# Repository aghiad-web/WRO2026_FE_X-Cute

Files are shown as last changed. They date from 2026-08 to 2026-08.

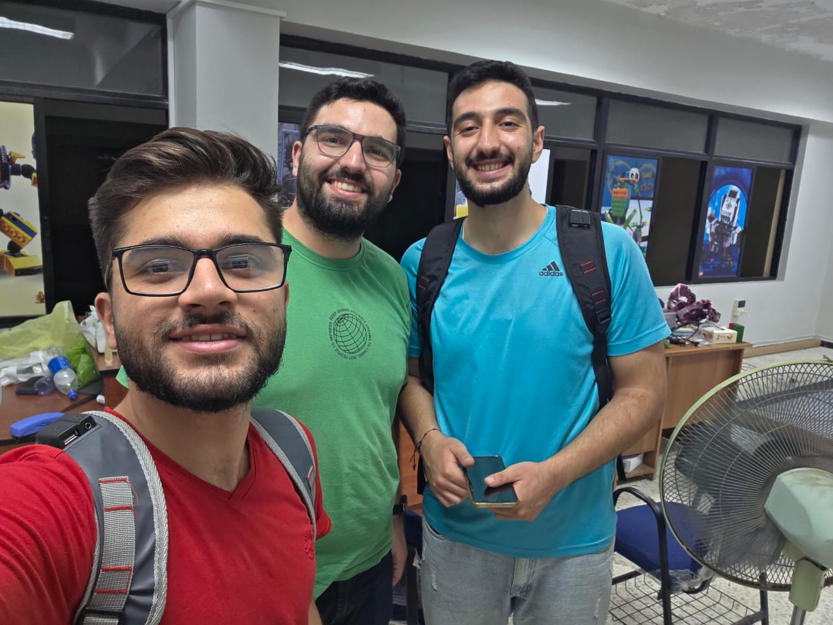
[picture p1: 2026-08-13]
t-photos/Team Photo .jpeg

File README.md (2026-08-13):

# WRO 2026 — Future Engineers | Team X-CUTE

Engineering documentation for the self-driving vehicle built by **Team X-CUTE** for the World Robot Olympiad 2026 Future Engineers category.

---

## Content

| Folder | Description |
|---|---|
| `t-photos` | Team photos — one official group photo and one informal/fun photo |
| `v-photos` | Vehicle photos from all six angles (front, back, left, right, top, bottom) |
| `video` | Link to the driving demonstration videos |
| `schemes` | Electromechanical schematics — wiring diagrams, PCB schematic and layout |
| `src` | All source code — Raspberry Pi vision/control scripts and STM32 firmware |
| `models` | 3D-printable models (STL) and SolidWorks source files for custom parts |
| `other` | Supporting files — datasheets, cost report, assembly notes |

---

## 1. Introduction

Our robot bridges advanced computer vision for strategic decision-making with real-time motion control. The vehicle uses an **Ackermann steering mechanism** and a hybrid sensory system that combines Time-of-Flight laser sensors for high-accuracy distance measurement with ultrasonic sensors acting as a fast-response safety and wall-following layer.

High-level visual perception runs on a **Raspberry Pi 5**, while an **STM32F411 microcontroller** executes real-time PID control. This separation ensures seamless navigation, dynamic obstacle dodging, and precise final parking.

---

## 2. The Team

**Team X-CUTE**

| Role | Name |
|---|---|
| Coach | Aghiad Jomah |
| Member | Mohamad Alzoubi |
| Member | Elias Kuzma |

Our team integrates embedded systems engineering with computer vision to build self-driving vehicles capable of analyzing their environment and making independent, reliable navigational decisions in dynamic conditions.

> Team photos are in [`t-photos`](t-photos).

---

## 3. Mobility Management

### 3.1 Chassis Design

The chassis was precision-designed in **SolidWorks** and fully 3D-printed, divided into three functional layers to balance weight distribution, mechanical isolation, and cable routing:

| Layer | Contents | Purpose |
|---|---|---|
| **Top (3rd)** | Custom PCB, STM32F411, camera module | Elevating the camera gives a clear, wide field of view for accurate track and pillar detection |
| **Middle (2nd)** | Raspberry Pi 5, motor driver | High-level processing and decision-making hub |
| **Bottom (1st)** | Drive motor, steering servo, battery | Places the heaviest components lowest for a low centre of gravity and stability during sharp cornering |

### 3.2 Custom 3D-Printed Parts

All source models are available in [`models`](models).

- **Three main chassis layers** — custom lightweight structure with pre-designed mounting holes, integrated standoffs, and optimised cable routing paths.
- **Ackermann steering knuckles** — designed to achieve the exact Ackermann geometry for our wheelbase, with optimised pivot points for maximum steering angle without wheel scrub.
- **DC motor mount** — secures the Ga25 motor and maintains alignment between the motor shaft and differential gear to prevent power loss.
- **Ultrasonic sensor holders** — set the mounting height and angle to detect track walls reliably while avoiding false floor reflections.
- **Laser sensor mounts** — hold the VL53L0X modules at a fixed angle for accurate pillar targeting.

### 3.3 Steering — Ackermann Geometry

Ackermann geometry allows the inner wheel to steer at a sharper angle than the outer wheel, minimising tire slip and scrub while maintaining an optimal centre of rotation.

Where `w` is the track width, `l` the wheelbase, `φᵢ` the inner wheel angle, `φₒ` the outer wheel angle, and `r` the distance from the instantaneous centre of curvature (ICC) to the vehicle centre:

```
tan(φ)  = l / r
tan(φᵢ) = l / (r − w/2)
tan(φₒ) = l / (r + w/2)

φᵢ = arctan( 2l·sin(φ) / (2l·cos(φ) − w·sin(φ)) )
φₒ = arctan( 2l·sin(φ) / (2l·cos(φ) + w·sin(φ)) )
```

Actuation uses a **DYNAMIXEL XL330 smart servo**. Unlike standard RC servos driven by PWM, it communicates over a half-duplex serial bus, letting the STM32 send precise angular commands and read back the exact motor position.

### 3.4 Drivetrain

| Component | Specification |
|---|---|
| **Drive motor** | Ga25 brushed DC gear motor — 12 V, ≈600 RPM, ≈10:1 gearbox, ≈0.4 kg·cm continuous torque, ≈1.2 A stall |
| **Steering servo** | DYNAMIXEL XL330 — 5 V, ≈5.3 kg·cm stall torque, UART/TTL half-duplex, internal PID with position/velocity/load/temperature feedback |
| **Differential** | Gear differential on the rear axle — allows the outer wheel to rotate faster while cornering, preventing skid |
| **Wheels** | Silicone — high grip and traction, minimising slippage under acceleration and braking |

---

## 4. Power and Sense Management

### 4.1 Sensors

| Sensor | Qty | Role |
|---|---|---|
| **VL53L0X** ToF laser | 2 | Primary sensor for precise dynamic pillar dodging — mm-level accuracy, up to 200 cm, 50 Hz, immune to ambient light |
| **US-100** ultrasonic | 3 | Wall-following and safety net — 2–450 cm, built-in temperature compensation for stable readings regardless of motor or ambient heat |
| **BNO085** 9-DoF IMU | 1 | Heading estimation via on-chip sensor fusion — ≈1.5° static / ≈3.5° dynamic accuracy, resistant to electromagnetic interference |
| **FANTECH LUMINOUS C30** camera | 1 | USB webcam, 2K @ 30 FPS, ≈106° ultra-wide FOV — line and pillar detection via OpenCV |

### 4.2 Drivers

- **IBT-4 DC Motor Driver** — high-current MOSFET H-bridge, 5–15 V, up to 50 A peak. Provides large headroom over the Ga25's 1.2 A stall current and protects against back-EMF during active braking. Interfaces directly with 3.3 V STM32 logic, no level shifters required.
- **Waveshare Serial Bus Servo Driver** — converts standard full-duplex UART to the half-duplex single-wire bus the XL330 requires, with hardware-level automatic TX/RX direction switching. Routes servo power separately, isolating motor current from logic circuits.

### 4.3 Controllers

Our system uses a **Hybrid Control Architecture** that separates high-level processing from low-level real-time motion control.

**Raspberry Pi 5 (8 GB)** — the brain. Runs Python control scripts and OpenCV computer vision, processes camera frames, applies the Y-axis depth-sorting algorithm for red and green pillars, and sends strategic commands to the STM32 over UART. The 2.4 GHz quad-core Cortex-A76 and 8 GB LPDDR4X allow 2K-resolution processing at high frame rates without bottlenecks.

**STM32F411 (BlackPill)** — the muscle. Receives strategic commands over UART and translates them into precise PWM motor signals, handles ultrasonic hardware interrupts, and reads the IMU. Linux is not designed for hard real-time tasks; the STM32 provides **deterministic execution**, ensuring PID calculations, motor updates, and sensor reads occur with microsecond precision and no jitter. Its hardware FPU accelerates the floating-point math the control loops require.

### 4.4 Power Management

The electrical system follows a **"Separation of Power Domains"** philosophy:

- **Logic power** — the Raspberry Pi and its camera run from a dedicated 20 W power bank. This complete isolation prevents OS brownouts caused by sudden current draw from the motors.
- **Actuator power** — a 3S Li-Po (11.1 V, 2200 mAh, 30C) supplies the lower layer. The high discharge rate delivers burst current for the motor and servo during acceleration and sudden stops without voltage sag.
- **Voltage regulation** — an XL4015 DC-DC buck converter steps 11.1 V down to a clean, regulated 5 V for the STM32 and sensors, at up to 96% efficiency with thermal shutdown and short-circuit protection.

<details>
<summary><b>Full current budget</b></summary>

| Component | Qty | Supply | Idle | Active | Peak/Stall |
|---|---|---|---|---|---|
| Raspberry Pi 5 (8 GB) | 1 | 5.0 V | ~600–800 mA | ~1.5–2.0 A | up to 5.0 A |
| FANTECH C30 camera | 1 | 5 V (Pi USB) | — | ~150–250 mA | ~300 mA |
| STM32F411 | 1 | 3.3 / 5 V | ~10 mA | ~25–35 mA | ~50 mA |
| BNO085 IMU | 1 | 3.3 V | ~3 mA | ~10–15 mA | — |
| US-100 ultrasonic | 3 | 5.0 V | < 2 mA | ~3–5 mA | — |
| VL53L0X laser | 2 | 3.3–5.0 V | < 5 µA | ~20 mA | ~40 mA |
| DYNAMIXEL XL330 | 1 | 5.0 V | ~15 mA | ~150–300 mA | ~1.5 A |
| Ga25 DC motor | 1 | 12 V | — | ~100–400 mA | ~1.2 A |
| IBT-4 driver | 1 | 5 V logic / 12 V load | ~2 mA | driver losses | 50 A peak rating |
| Waveshare servo driver | 1 | 5.0 V | ~2 mA | servo load pass-through | — |
| XL4015 converter | 1 | 12 V in / 5 V out | ~5 mA | load dependent | 5 A peak rating |

</details>

### 4.5 Custom PCB

To eliminate the unreliability of loose jumper wires and breadboards, we designed a custom PCB that acts as the central nervous system of the hardware — routing power and data between the STM32, sensor arrays, motor drivers, and the XL4015 power module.

The schematic enforces complete isolation between logic circuits and high-current actuators, with properly sized power traces, pull-up resistors on the I²C lines, and organised header pins. The layout accounts for EMI and thermal dissipation: the XL4015 and BlackPill are placed to minimise signal travel distance, and extensive copper ground pours provide a common reference and heat spreading.

> Schematics and layout files are in [`schemes`](schemes).

---

## 5. Obstacle Management

### 5.1 System Architecture

Rather than heavy middleware, we use a lightweight **Master–Slave architecture** over direct UART:

- **Master node** — Raspberry Pi 5 running Python. Captures frames, processes them via OpenCV, and issues strategic commands (`TURN_LEFT`, `DODGE_RIGHT`, …).
- **Execution node** — STM32F411. Receives short string commands and folds them into a **non-blocking Finite State Machine** that updates motor speeds and PID offsets without halting distance or IMU sensor reads.

### 5.2 Open Challenge — "Direction Lock"

The goal is three laps without wall contact in the shortest time. We run a wall-following algorithm on the ultrasonic sensors, driving the error between right and left distances toward zero with a PID controller.

For corners, the camera does not re-evaluate colour at every turn. On start, it monitors the floor: an **orange line first locks the direction as Clockwise**; a **blue line first locks Counter-Clockwise**. For the remaining 11 corners the robot turns according to the locked direction as soon as any line colour is seen — eliminating visual confusion and guaranteeing track stability.

### 5.3 Image Processing

Frames from the tilt-down camera are converted from RGB to **HSV** to resist colour fluctuation under changing light. We apply masks isolating the four relevant colours (blue, orange, red, green), run morphological filters to remove noise, and extract bounding boxes to determine each element's position and size in frame.

### 5.4 Obstacle Challenge — Y-Axis Depth Sorting

Pillars require higher spatial accuracy than corners. To handle complex scenes — for example red and green pillars in the same frame — we developed the **Y-Axis Depth Sorting** algorithm:

1. Collect the coordinates of all detected pillars and sort them in descending order by the lowest point of their bounding box (`bottom_y`).
2. Ignore all distant pillars; interact only with the pillar of highest `Y` value — the one nearest the front of the robot.
3. If the nearest pillar is **red**, the Pi sends `DODGE_RIGHT`; if **green**, `DODGE_LEFT`. The STM32 translates the command into a dynamic `Lane_Offset` bias inside the distance-sensor PID equation, smoothly hugging the corresponding wall.

Because the dodge is expressed as a PID bias rather than a discrete manoeuvre, the robot performs continuous slalom movement without ever needing to stop.

---

## 6. Performance Videos

| Challenge | Video |
|---|---|
| Open Challenge | *[link]* |
| Obstacle Challenge | *[link]* |

---

## 7. Problems We Encountered

| Problem | Solution |
|---|---|
| **Camera field of view** — the standard Pi camera's narrow FOV made it hard to see the full track width or spot peripheral pillars in time. | Replaced with the FANTECH C30 wide-angle webcam, letting the vision pipeline capture surrounding detail and recognise obstacles from a safe distance. |
| **Ackermann steering angle limits** — the initial mechanism capped our maximum steering angle, widening the turning radius and pushing the robot toward outer walls. | Redesigned the knuckles and tie rods in SolidWorks with optimised pivot points and lever lengths, significantly increasing front-wheel range of motion while preserving correct Ackermann intersection. |
| **Frame flickering** — room lighting and fluorescent lamp frequency destabilised our colour masks. | Disabled auto white balance and set shutter speed and exposure programmatically via OpenCV to match ambient lighting frequency. |
| **Processor data-flow desync** — continuous UART streaming from the Pi overflowed the STM32 buffer, delaying motor response. | Replaced streaming with a lightweight event-based protocol that sends short commands only on state change, plus a non-blocking FSM on the STM32 so serial reads never halt other operations. |
| **Merging pillar contours** — closely spaced pillars merged into one contour from the low camera perspective, misread as a single obstacle. | Raised the camera to the third layer and optimised its tilt-down angle, restoring visual separation and letting depth sorting work accurately. |

---

## 8. Improvements and Future Modifications

**Mobility**
- **Aluminium CNC upgrade** — replace the printed steering knuckles and motor mounts with CNC-machined aluminium to eliminate joint flex at speed and improve steering precision.
- **Differential upgrade** — move to a sealed metal differential with lubricating fluid to cut internal friction and improve torque transfer efficiency.

**Power and Sensing**
- **Battery Management System** — integrate a BMS module into the PCB to monitor individual cell voltages and real-time current draw, reported over UART so the system can dynamically cap top speed and prevent voltage drops.
- **LiDAR integration** — a 2D LiDAR (e.g. RPLIDAR) would give a 360° point cloud, reducing discrete sensor count and improving localisation accuracy within the track.

**Obstacle Management**
- **Deep learning for vision** — replace HSV colour masking with a lightweight model such as YOLO, making detection immune to drastic lighting changes and colour distortion.
- **Path caching** — pillar placement is fixed across all three laps under WRO rules. Memorising pillar colours and coordinates during a slower first lap would let laps two and three run at maximum speed without re-evaluating every frame.

---

## 9. Conclusion

Our goal was never simply to build a robot that completes the track, but to engineer a system where every component was chosen for a defensible reason and every subsystem validated through testing rather than assumption.

The defining decision was the **Hybrid Control Architecture** — separating high-level perception on the Raspberry Pi from hard real-time execution on the STM32. This let each processor do what it does best: computer vision without timing pressure, and deterministic PID control without operating-system jitter.

Equally important was iterative refinement. Nearly every subsystem here exists in its current form because an earlier version failed under test — the steering knuckles were redesigned after we hit our geometry's angular limits, the camera moved up a layer after merged contours revealed the cost of a low perspective, and the communication protocol was rewritten after buffer overflows appeared. Each failure taught us more than a first-attempt success would have.

Beyond the technical outcome, this project developed our capabilities in mechanical design, PCB layout, embedded firmware, computer vision, and the systems thinking required to make these disciplines work together.

---

*Team X-CUTE — WRO 2026 Future Engineers*

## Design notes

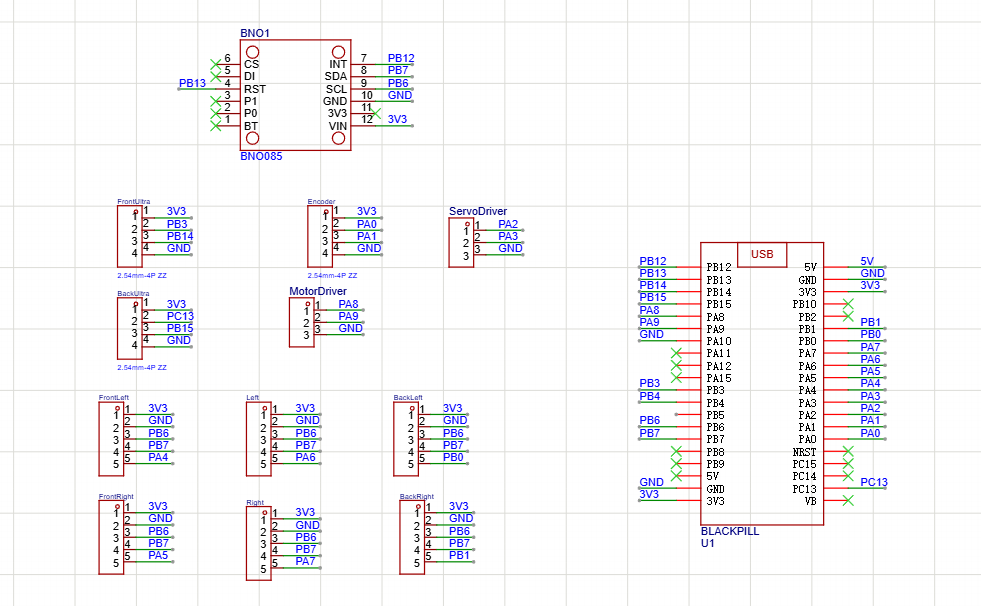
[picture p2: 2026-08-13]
schemes/Schematic.png

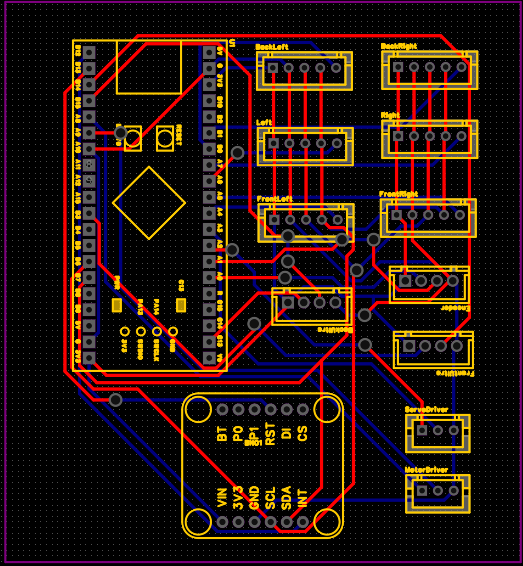
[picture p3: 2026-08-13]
schemes/PCB.png

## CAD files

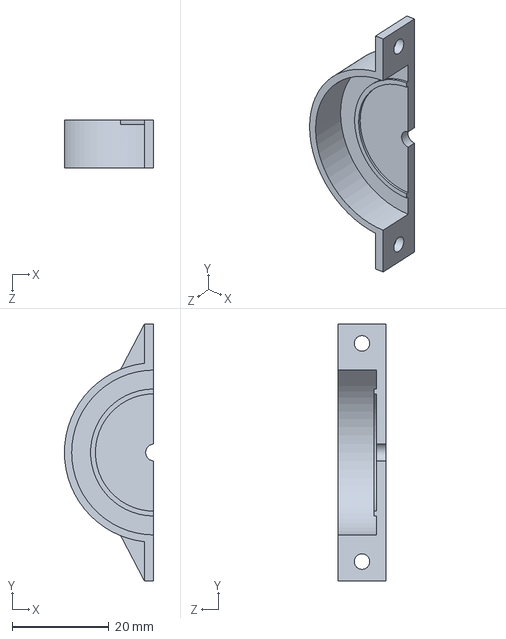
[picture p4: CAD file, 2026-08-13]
models/mold30mmP1.SLDPRT
18.4 x 53.0 x 10.0 mm

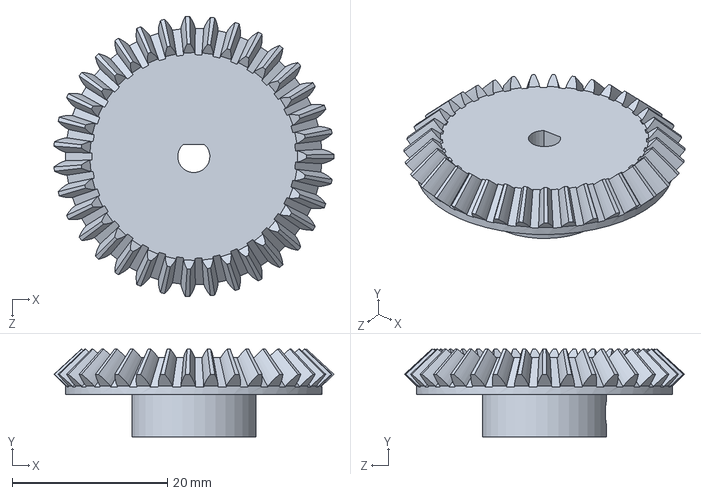
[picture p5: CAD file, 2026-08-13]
models/drive gear.SLDPRT
36.1 x 11.3 x 36.1 mm

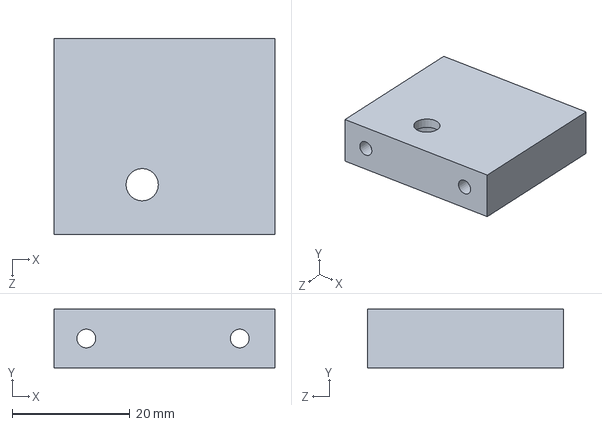
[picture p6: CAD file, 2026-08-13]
models/Q2.SLDPRT
37.6 x 10.0 x 33.4 mm

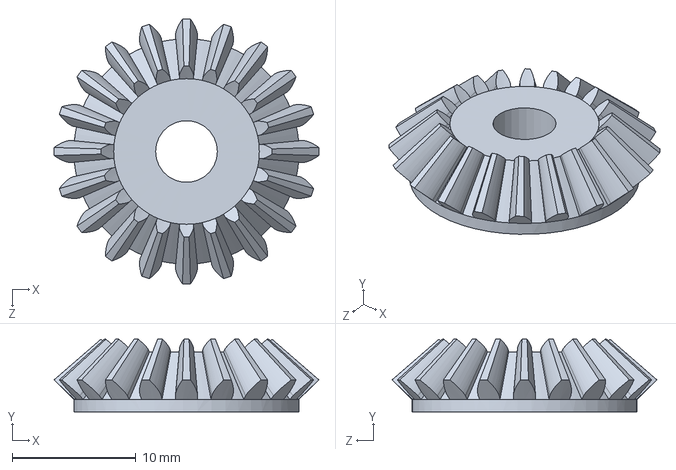
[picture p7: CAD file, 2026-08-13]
models/20T bevel.SLDPRT
21.4 x 5.87 x 21.4 mm

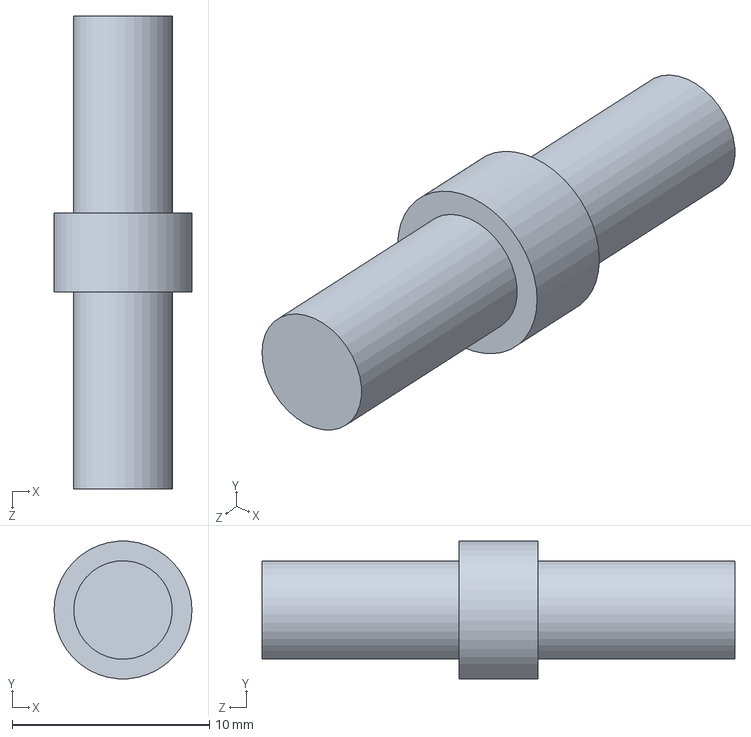
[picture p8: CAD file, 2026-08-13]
models/rod.SLDPRT
7.00 x 6.98 x 24.0 mm

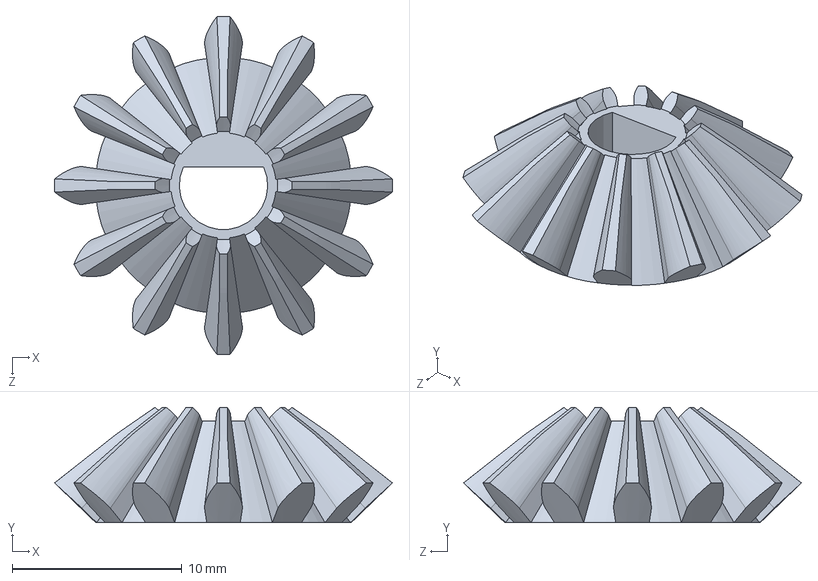
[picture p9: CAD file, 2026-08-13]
models/Part Studio 1 - Bevel 1.5M 12T 45deg.SLDPRT
19.9 x 6.79 x 19.9 mm

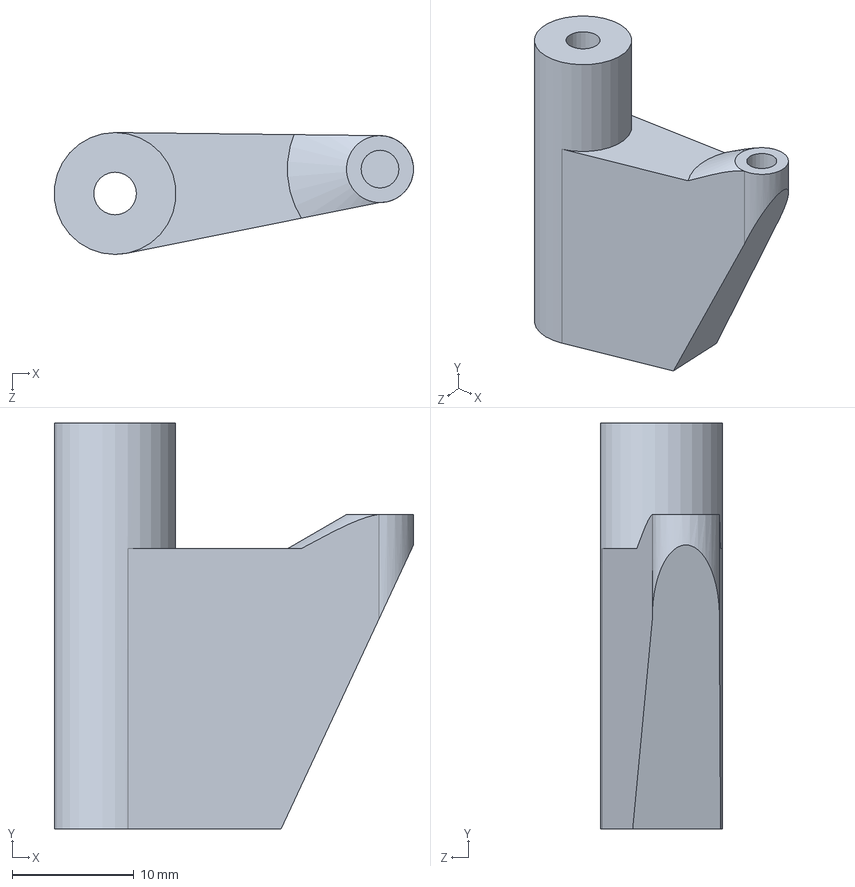
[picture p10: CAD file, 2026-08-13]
models/idlers2.0.SLDPRT
29.5 x 33.3 x 10.0 mm

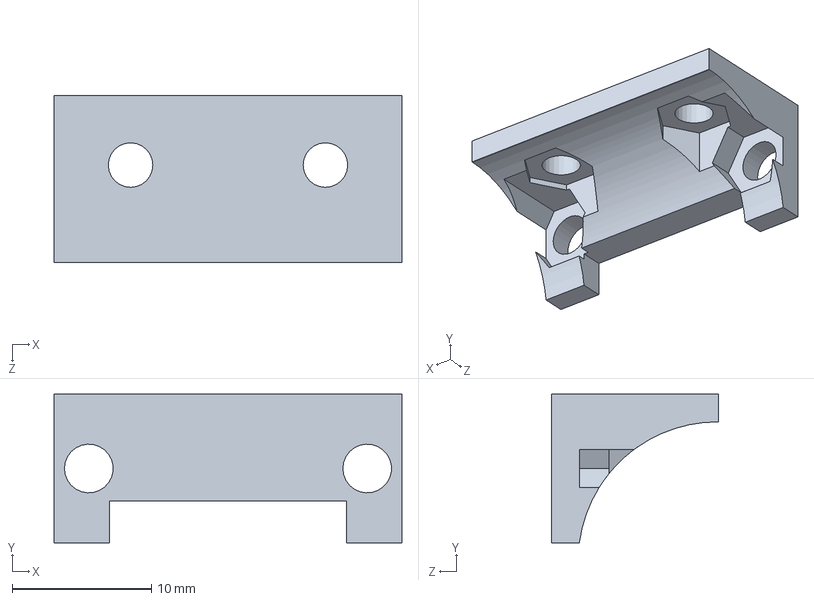
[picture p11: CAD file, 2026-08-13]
models/ultraholder.SLDPRT
25.0 x 10.7 x 12.0 mm

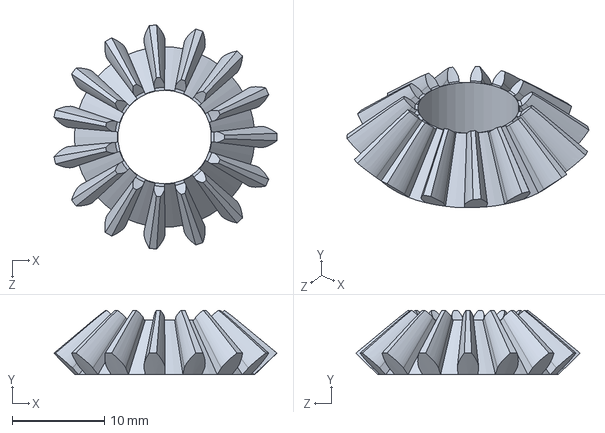
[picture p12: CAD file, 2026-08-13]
models/Part Studio 1 - Bevel 1.5M 15T 45deg.SLDPRT
24.2 x 6.99 x 24.3 mm

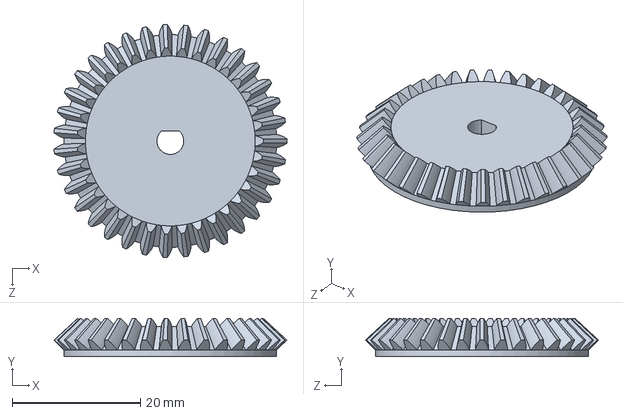
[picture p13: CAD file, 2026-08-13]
models/Part Studio 1 - Bevel 1M 35T 45deg.SLDPRT
36.4 x 5.98 x 36.4 mm

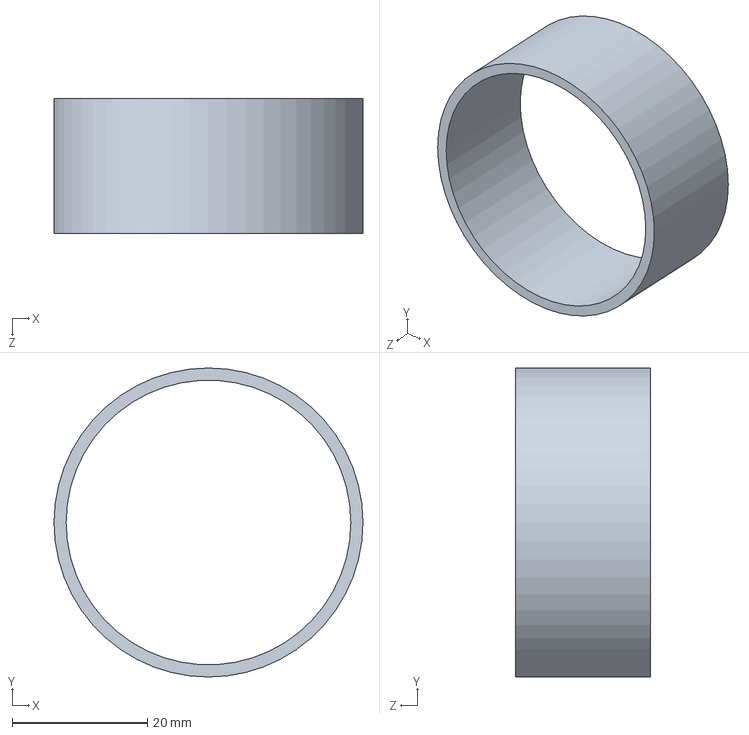
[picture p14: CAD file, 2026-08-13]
models/mold40mmP2.SLDPRT
45.7 x 45.7 x 20.0 mm

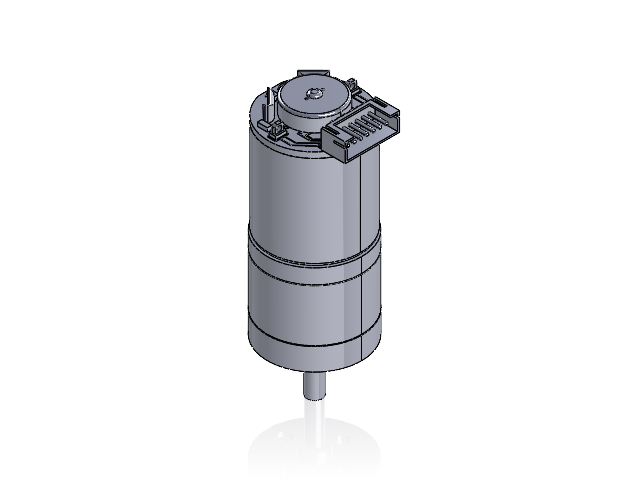
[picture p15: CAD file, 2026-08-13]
models/ga25-370_gear_motor.SLDASM
ga25-370_gear_motor1_1.stp
ga25-370_gear_motor2_1.stp
ga25-370_gear_motor3_1.stp
ga25-370_gear_motor4_1.stp
ga25-370_gear_motor5_1.stp
ga25-370_gear_motor6_1.stp
ga25-370_gear_motor7_1.stp
ga25-370_gear_motor8_1.stp

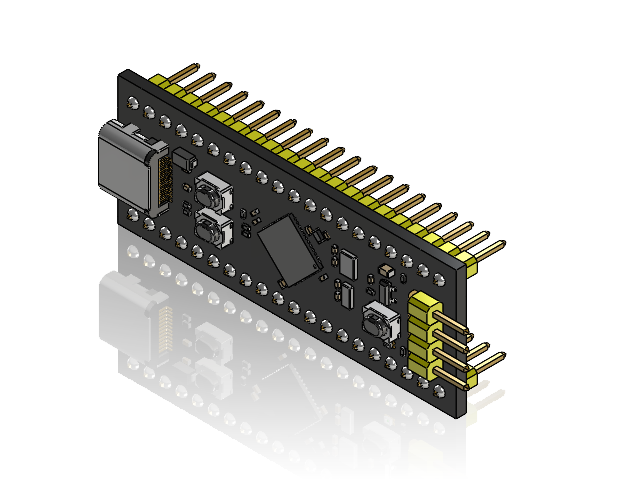
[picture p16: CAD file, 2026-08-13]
models/Black Pill.SLDASM
Black Pill1.step
Black Pill2.step
Black Pill3.step
Black Pill4.step
Black Pill5.step
Black Pill6.step
Black Pill7.step
Black Pill8.step
Black Pill9.step
Black Pill10.step
Black Pill11.step
Black Pill12.step
Black Pill13.step
Black Pill14.step
Black Pill15.step
Black Pill16.step
Black Pill17.step
Black Pill18.step
Black Pill19.step
Black Pill20.step
Black Pill21.step
Black Pill22.step
Black Pill23.step
Black Pill24.step
Black Pill25.step
Black Pill26.step
Black Pill27.step
Black Pill28.step
Black Pill31.step
Black Pill32.step
Black Pill33.step
Black Pill34.step
Black Pill35.step
Black Pill36.step
Black Pill37.step
Black Pill38.step
Black Pill39.step

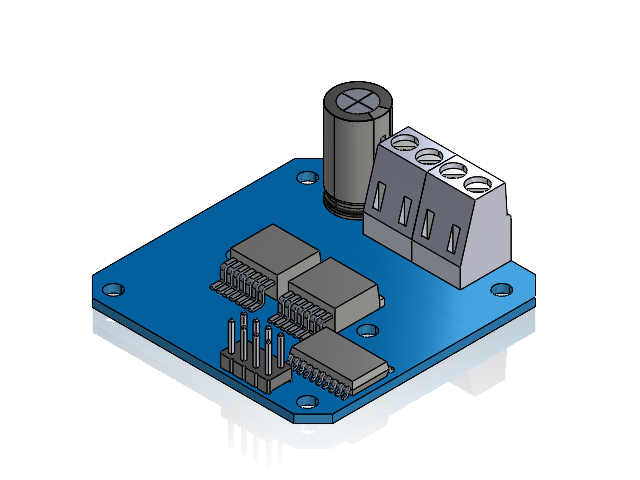
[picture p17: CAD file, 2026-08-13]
models/BTS7960 43A HIGH POWER H BRIDGE MODULE.SLDASM
PCB, BTS7960 43A HIGH POWER H BRIDGE MODULE.STEP
ALUMINUM ELECTROLYTIC CAPACITOR, 330 uF, BTS7960 43A HIGH POWER H BRIDGE MODULE.STEP
BTN7960 IC, BTS7960 43A HIGH POWER H BRIDGE MODULE.STEP x 2
NXP 74HC244D, BUFFER AND LINE DRIVER, BTS7960 43A HIGH POWER H BRIDGE MODULE.STEP
8 PIN HEADER, IC, BTS7960 43A HIGH POWER H BRIDGE MODULE.STEP
EUROSTYLE TERMINAL BLOCK 2 POS 5.0 MM RA PLUG, BTS7960 43A HIGH POWER H BRIDGE MODULE.STEP x 2

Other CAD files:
models/jga25-370.SLDASM
models/Ackerman.SLDASM
models/XL330.SLDASM
models/Q1.SLDPRT
models/25T bevel.SLDPRT
models/7804K108_Corrosion-Resistant 440C Stainless Steel Ball Bearing.SLDPRT
models/Lower_part-1.SLDPRT
models/Part Studio 1 - Bevel 1M 18T 45deg.SLDPRT
models/Part Studio 1 - Bevel 1M 19T 45deg.SLDPRT
models/Part Studio 1 - Bevel 1M 34T 45deg.SLDPRT
models/Part Studio 1 - Bevel 1M 45T 45deg.SLDPRT
models/Uper_Face.SLDPRT
models/axle.SLDPRT
models/back sensors.SLDPRT
models/battery.SLDPRT
models/conector3.SLDPRT
models/differential_Cage11.SLDPRT
models/front sensors.SLDPRT
models/idlers.SLDPRT
models/laser holder skewed.SLDPRT
models/laser holder.SLDPRT
models/link-1.SLDPRT
models/mold30mmP2.SLDPRT
models/mold40mmP1.SLDPRT
models/motorBracket.SLDPRT
models/rod 3mm.SLDPRT
models/stls/Lower_part-1.STL
models/stls/Part Studio 1 - Bevel 1.5M 12T 45deg.STL
models/stls/Q1.STL
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

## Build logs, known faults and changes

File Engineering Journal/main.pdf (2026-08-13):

## WRO 2026 - FUTURE ENGINEERS

## X-Cute Team- Documentary

## GitHUB (https://github.com/aghiad-web/WRO2026_FE_X-Cute)

## Aghiad Jomah (coach)

## Mohamad Alzoubi

## Elyas Kuzma

## المحتويات

4 | Introduction
5 | Our Team | 1.
6 | Our Robot | 2.
6 | Top Layer (Third Layer): | 2.1.
6 | Middle Layer (Second Layer): | 2.2.
6 | Bottom Layer (First Layer): | 2.3.
7 | Mobility Management | 3.
7 | Vehicle Main Body | 3.1.
7 | 3D-Designed Parts | 3.1.1.
8 | Motion Mechanism | 3.2.
10 | Power and Sense Management | 4.
11 | Sensors | 4.1.
11 | Laser Sensors (VL53L0X - ToF Sensors): | 4.1.1.
12 | Ultrasonic Sensors (US-100): | 4.1.2.
Inertial Measurement Unit (BNO085 IMU): | 4.1.3.
12
13 | Camera (FANTECH LUMINOUS C30): | 4.1.4.
14 | Motor Drivers | 4.2.
14 | DC Motor Driver (IBT-4): | 4.2.1.
Servo Driver (Waveshare Serial Bus | 4.2.2.
14 | Servo Driver):
15 | Controllers and Microprocessors | 4.3.
15 | Raspberry Pi 5 (8GB RAM): | 4.3.1.
16.........STM32F411 Microcontroller (BlackPill): | 4.3.2.
17 | Power Management | 4.4.
21 | Obstacle Management | 5.
21........ System Architecture & Communication | 5.1.
21 | Open Challenge | 5.2.
21 | "Direction Lock" Algorithm: | 5.2.1.
21 | Image Processing | 5.3.
21 | Region of Interest & Contouring: | 5.3.1.
22 | Obstacle Challenge | 5.4.
22 | Performance Videos | 5.5.
22 | Problems We Encountered | 5.6.

24...... Improvements and future modifications | 6.
25 | 7. Conclusion

## Introduction

In this report, we present our self-driving system developed for the WRO 2026 - Future Engineers category. Our robot bridges advanced computer vision for strategic decision-making with real-time motion control. The vehicle features an Ackermann steering mechanism and a hybrid sensory system combining the precision of Laser sensors for highly accurate distance measurement and maneuvering, alongside Ultrasonic sensors that act as a fast-response safety system for distance verification. High-level visual perception and processing are powered by a Raspberry Pi, while an STM32 microcontroller executes real-time PID control algorithms. The software architecture is engineered to ensure seamless navigation, dynamic obstacle dodging, and precise final parking.

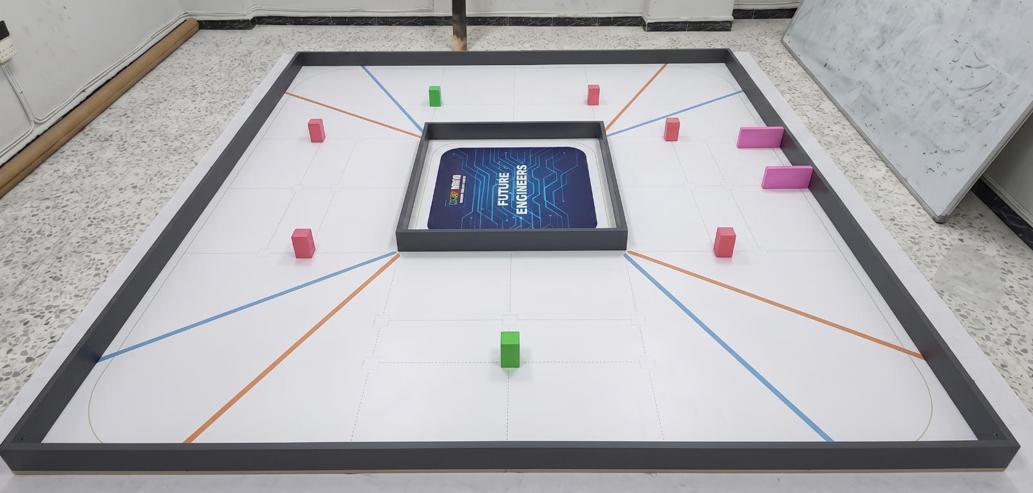
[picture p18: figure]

## 1.Our Team

We are team X-CUTE. Our team represents a product of technical dedication and engineering passion, focused on integrating advanced Embedded Systems engineering with Computer Vision algorithms to build self-driving vehicles capable of analyzing their environment and making independent, reliable navigational decisions in dynamic environments.

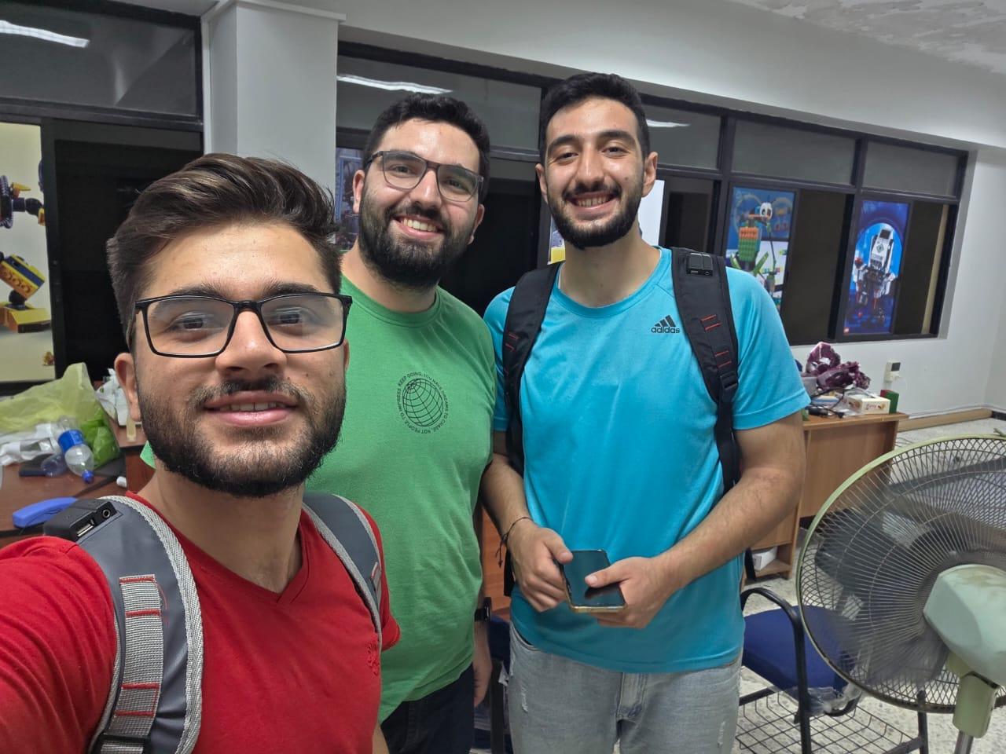
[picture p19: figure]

## 2.Our Robot

Our robot is a four-wheeled autonomous vehicle built on a robust, custom-designed chassis modeled in SolidWorks. The structure consists of three main layers to ensure optimal weight distribution, efficient organization of electronic and mechanical components, and streamlined cable management:

2.1.Top Layer (Third Layer):

Serves as the real-time control and vision platform. This layer houses the custom Printed Circuit Board (PCB), the STM32 microcontroller responsible for executing low-level control algorithms, and the camera module. Elevating the camera to this level ensures a clear, unobstructed, and wide Field of View (FoV) for highly accurate track and pillar detection.

### 2.2. Middle Layer (Second Layer):

Acts as the high-level processing and decision-making hub. This layer hosts the Raspberry Pi, which handles computer vision and complex data processing, alongside the Motor Driver.

2.3.Bottom Layer (First Layer): Dedicated to the drivetrain, steering mechanism, and power source. This arrangement ensures a low Center of Gravity (CoG) to enhance vehicle stability during fast maneuvers and sharp cornering. It contains the main drive motor, the smart steering actuator (Servo), and the main battery that powers the entire system.

## 3.Mobility Management

### 3.1. Vehicle Main Body

The robot relies on a robust chassis entirely precision-designed using SolidWorks.

The structure is divided into three functional layers, which were fully

manufactured using 3D printing technology to ensure optimal weight distribution,

mechanical isolation, and ease of wiring for the custom Printed Circuit Board

(PCB). The design focuses on balancing durability and lightweight properties,

allowing the robot to withstand vibrations from rapid movements.

3.1.1. 3D-Designed Parts

To ensure seamless integration and minimize overall weight, all critical mechanical components, including the main body layers, were custom-designed and manufactured using 3D printing technology. Each part was meticulously engineered to serve a specific function within the robot's ecosystem:

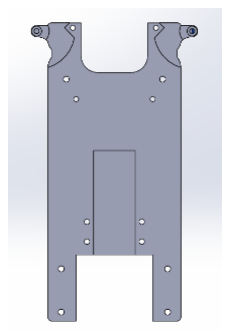
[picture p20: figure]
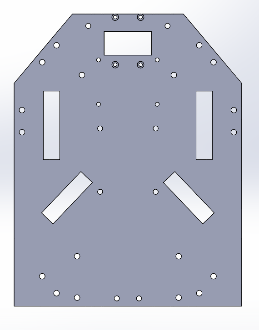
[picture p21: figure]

- The Three Main Chassis Layers (Top, Middle, Bottom): 3D printing the main body allowed us to create a custom, lightweight structure with pre-designed mounting holes, integrated standoffs, and optimized cable routing paths that Ackermann Steering Joints: Custom-designed to achieve the exact Ackermann geometry required for our wheelbase. 3D printing these knuckles allowed us to optimize the pivot points, ensuring maximum steering angles and precise cornering without wheel scrub.

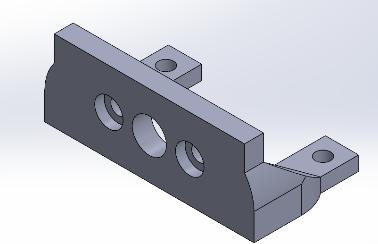
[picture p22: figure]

- DC Motor Mount: Engineered to firmly secure the Ga25 main drive motor to the bottom layer. It absorbs operational motor shaft and the differential gear to prevent any power loss.

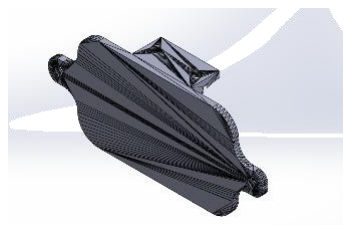
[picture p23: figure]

- Ultrasonic Sensor Holders: Specially designed brackets to mount the US-100 sensors to the sides and front of the height and angle to detect track walls effectively while avoiding false sound-wave reflections from the floor.

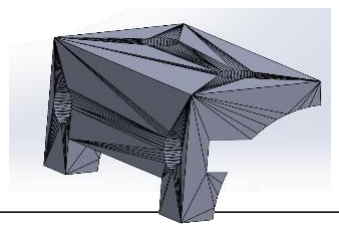
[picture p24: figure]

- Laser Sensor Mounts: Custom mounts created to hold the guarantees highly accurate targeting and distance measurement for the colored pillars during the Obstacle Challenge.

3.2.Motion Mechanism

### 3.2.1. Ackermann Steering Mechanism:

To ensure smooth and precise responsiveness during turns, our vehicle employs Ackermann steering geometry. This system allows the inner wheel to steer at a sharper angle than the outer wheel, minimizing tire slip and scrub while maintaining an optimal center of rotation. To mechanically actuate this system, we integrated the DYNAMIXEL XL330 smart servo motor. This actuator is characterized by its high-resolution positioning, consistent torque, and serial communication (UART) support, enabling it to receive highly accurate and instantaneous steering angles directly from the STM32 microcontroller.

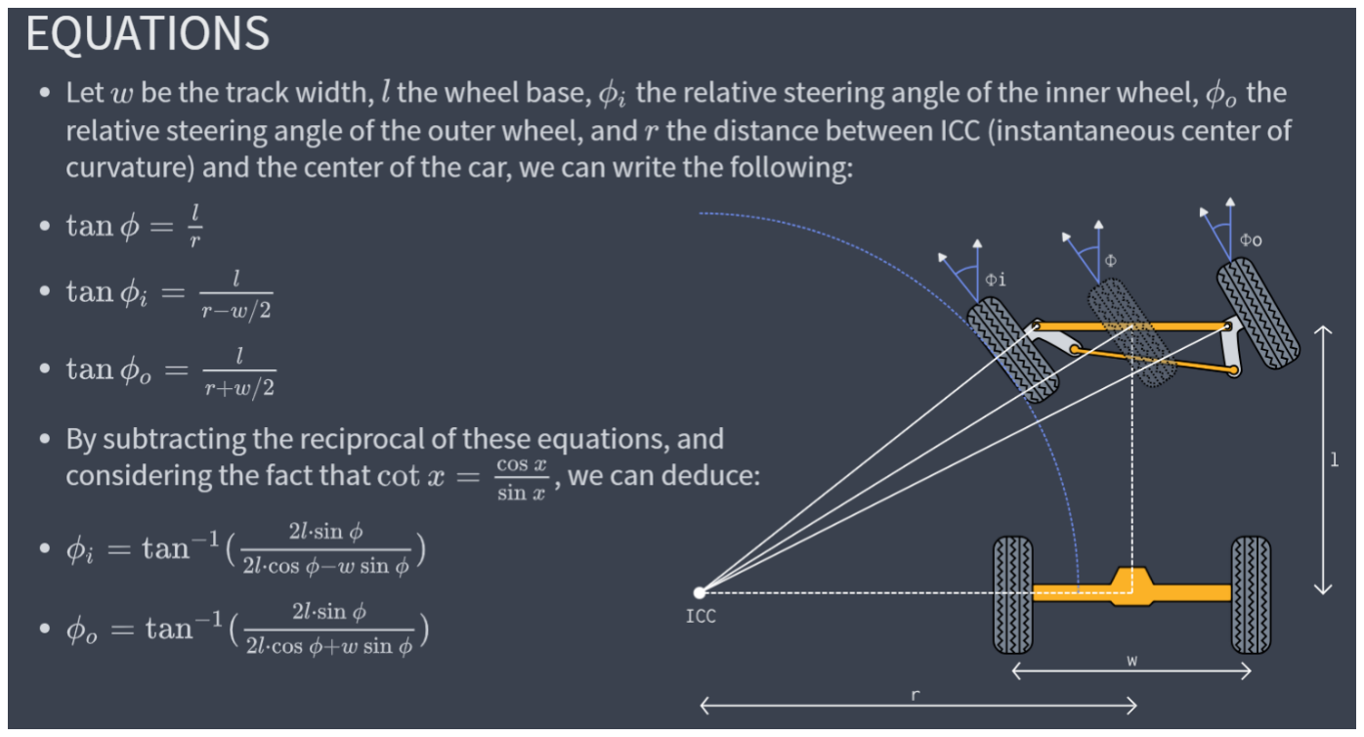
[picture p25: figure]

### 3.2.2. Driving Motor:

The vehicle is powered by a Ga25 DC motor operating at 12 Volts. Equipped with a gearbox, it delivers a rotational speed of 600 RPM, providing the robot with an excellent balance between torque and the top speed required to traverse the track sections efficiently.

### 3.2.3. Differential Gear:

To ensure a smooth distribution of kinetic energy to the rear wheels, we implemented a Differential Gear connecting the motor to the drive axle. This mechanism allows the outer wheel to rotate faster than the inner wheel while cornering, preventing the robot from skidding, improving maneuverability, and maintaining movement stability.

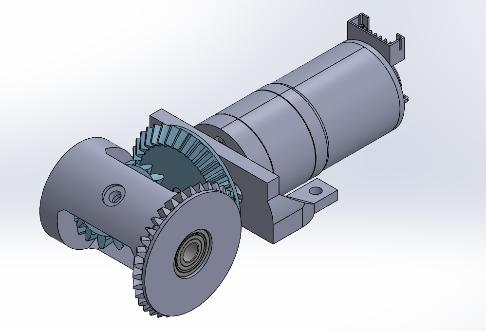
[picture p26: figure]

### 3.2.4. Wheels:

The robot is equipped with Silicone wheels. This material provides exceptional grip and traction on the track surface, minimizing slippage and translating the motor's torque into effective acceleration and immediate active braking response.

### 3.2.5. Driving Motor: This is the DC-motor we are using in the robot. It is connected

to the differential mechanism to ensure a smooth distribution of kinetic energy to the rear wheels.

Ga25 DC Motor (12 V, 600 RPM)
Type: Brushed DC gear motor with metal gearbox Nominal Voltage: 12 V DC
Gear Ratio: ≈ 10:1
No-Load Speed: ≈ 600 RPM ; No-Load Current: ≈ 100 mA
Torque: Continuous ≈ 0.4 kg·cm , Stall ≈ 1.5 kg·cm Stall Current: ≈ 1.2 A
Mechanical: Diameter ≈ 25 mm ; 4 mm D-shaft ; Weight ≈ 85 g
Recommended Driver: IBT-4 Motor Driver (High-current MOSFET capable of handling Back EMF) Notes: Provides an optimal balance of top speed for

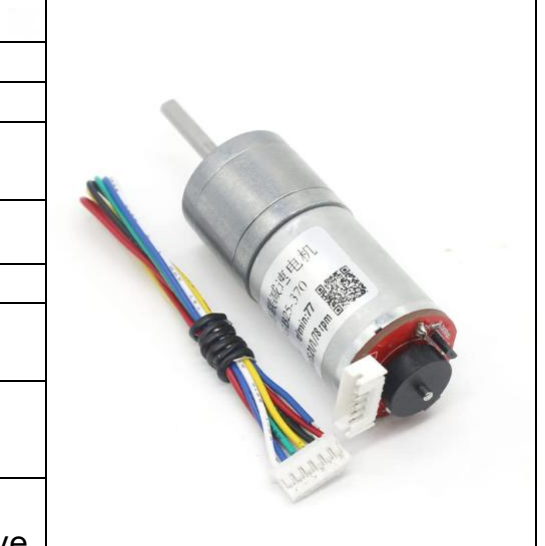
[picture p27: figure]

the straight track sections and sufficient torque to drive
the differential gear efficiently.

Table 1: Ga25 DC Motor (12 V, 600 RPM) – simplified datasheet view.

### 3.3. Steering Motor: For the steering mechanism, we used the DYNAMIXEL XL330 smart

servo due to its high-resolution positioning, consistent torque, and ability to provide real-time data feedback. Unlike standard RC servos that rely on simple PWM signals, this smart actuator communicates via a serial bus, allowing the STM32 microcontroller to send highly accurate angular commands and read the motor's exact position.

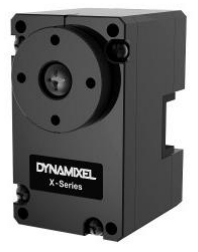
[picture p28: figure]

DYNAMIXEL XL330 Smart Servo

Type: Smart Actuator / Serial Bus Servo

Operating Voltage: 3.7 V – 6.0 V (Operated at 5 V) Stall Torque: ≈ 5.3 kg·cm (0.52 N·m at 5 V)

Speed: ≈ 57 RPM (0.17 s / 60° at 5 V)

Control Signal: Half-Duplex Asynchronous Serial (UART / TTL)
Feedback & Features: Internal PID controller ; Real-time feedback for Position, Velocity, Load, and Temperature Mechanical: Dimensions ≈ 20.0 × 34.0 × 26.0 mm ; Weight ≈ 18 g ; Engineering Plastic Gears

Recommended Driver: Waveshare Serial Bus Servo Driver (Converts standard UART to Half-Duplex Serial)

Table 2: DYNAMIXEL XL330 Smart Servo – simplified datasheet view.

3.4.Engineering Principles

3.4.1.Weight Distribution & CoG:

Components were strategically placed so that the heaviest parts (the Ga25 main motor, the DYNAMIXEL servo, and the battery) are located on the first (bottom) layer. This design ensures a low Center of Gravity (CoG), preventing the robot from tipping over during sharp maneuvers and maximizing the silicone tires' traction on the surface.

## 4.Power and Sense Management

This section explains how power consumption was managed across the robot's electrical components and details the hybrid sensing system used for data acquisition.

### 4.1. Sensors

To navigate safely and at high speeds, we integrated multiple sensing technologies to cover all blind spots and provide comprehensive environmental data:

### 4.1.1. Laser Sensors (VL53L0X - ToF Sensors):

These Time-of-Flight sensors provide highly accurate, millimeter-level distance measurements. They feature a rapid response time and immunity to ambient light variations, making them our primary sensors for precise, dynamic pillar dodging.

VL53L0X Time-of-Flight (ToF) Sensor

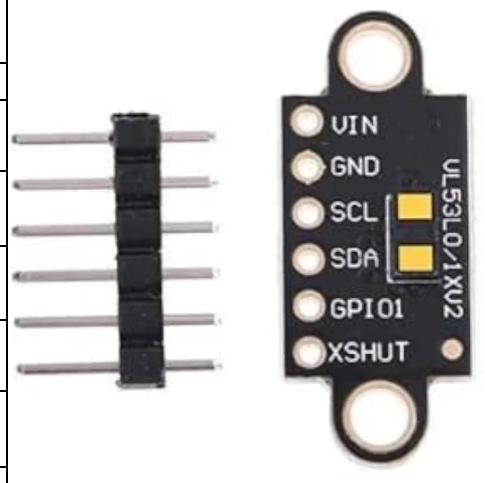
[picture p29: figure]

Type: Laser-ranging ToF sensor (940 nm VCSEL emitter)

Range: Up to 200 cm (2 meters)
Resolution: 1 mm ; Accuracy: ±3% ; Measurement Rate: Up to 50 Hz (High-speed mode)

Interface: I2C (up to 400 kHz)

Timing: Adjustable timing budget (typically 20 ms to 33 ms per reading)
Supply Voltage: 2.6 V – 3.5 V (Breakout boards accept 3.3V or 5V) ; Current: ≈ 20 mA (active)

Field of View: 25° Field of Illumination (FoI)

Size: Module size typically ≈ 10 × 13 mm (varies by breakout board)

Table 3: VL53L0X Time-of-Flight Sensor – simplified datasheet view.

### 4.1.2. Ultrasonic Sensors (US-100):

These act as a robust safety net and wall-following system. The US-100 features a built-in temperature sensor for the "Temperature Compensation" of the speed of sound. This ensures highly stable distance readings regardless of the heat generated by the motors or the ambient track temperature.

US-100 Ultrasonic Sensor
Type: Ultrasonic distance sensor with active temperature compensation
Range: 2 cm – 450 cm
Resolution: 1 mm ; Accuracy: High (Temperature Compensated)

Interface: GPIO (Trig/Echo) or UART mode

Timing: 10 µs trigger pulse ; max echo timeout ≈ 26 ms

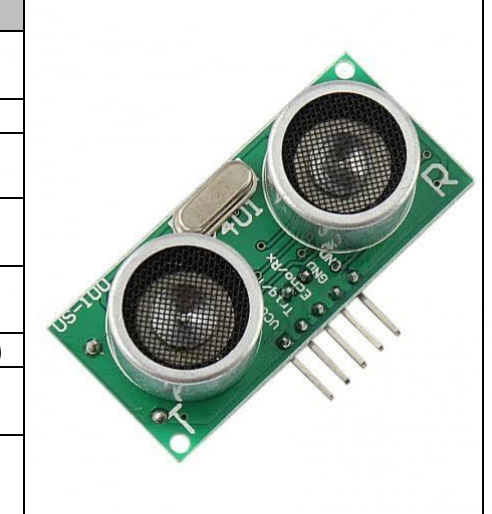
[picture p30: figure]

Supply Voltage: 2.4 V – 5.5 V ; Current: < 2 mA (quiescent)

Field of View: ≈ 15° beam angle

Size: 45 × 20 × 15 mm

Table 4: US-100 Ultrasonic Sensor – simplified datasheet view.

### 4.1.3. Inertial Measurement Unit (BNO085 IMU):

As mentioned earlier, we rely on this high-precision 9-DoF sensor to accurately estimate the target heading without suffering from electromagnetic interference.

BNO085 9-DoF IMU (Inertial Measurement Unit)
Type: 9-Axis System-in-Package (SiP) with integrated
Sensor Fusion processor
Sensors: 3-axis Accelerometer, 3-axis Gyroscope, 3-axis Magnetometer
Output Data: Quaternions, Euler Angles (Roll, Pitch, Yaw), Linear Acceleration, Gravity Vector

Interface: I2C (up to 400 kHz), SPI, and UART

Heading Accuracy: ≈ 1.5° (Static) ; ≈ 3.5° (Dynamic)

Operating Voltage: 3.3 V (Most breakout boards include a regulator for 3.3V – 5V operation)
Mechanical: Module size typically ≈ 20 × 25 mm (varies by breakout board)

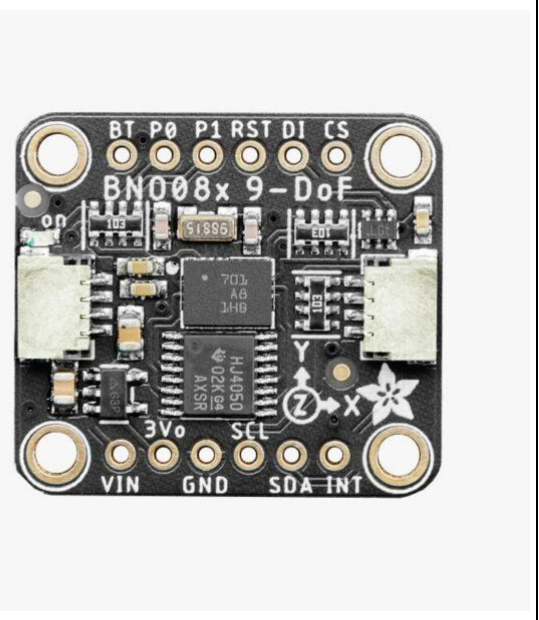
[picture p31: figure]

Table 5: BNO085 9-DoF IMU – simplified datasheet view.

### 4.1.4. Camera (FANTECH LUMINOUS C30):

Instead of standard ribbon-cable cameras, we opted for a high-definition USB web camera connected directly to the Raspberry Pi. This camera provides a wide field of view, crisp resolution (2K), and seamless plug-and-play integration with ROS and OpenCV to detect lines and pillars with utmost clarity.

FANTECH LUMINOUS C30 Web Camera

Type: High-Definition USB Web Camera

Maximum Resolution: 2K (Quad HD – 2560 × 1440 pixels) Frame Rate: Up to 30 FPS

Field of View (FOV): Ultra-Wide Angle (approx. 106°)

Interface: USB 2.0 (Plug-and-Play)

Lens: High-quality optical glass lens
Mechanical: Features a 360-degree rotating base, allowing for the precise tilt-down angle required when mounted on the
robot's third layer.

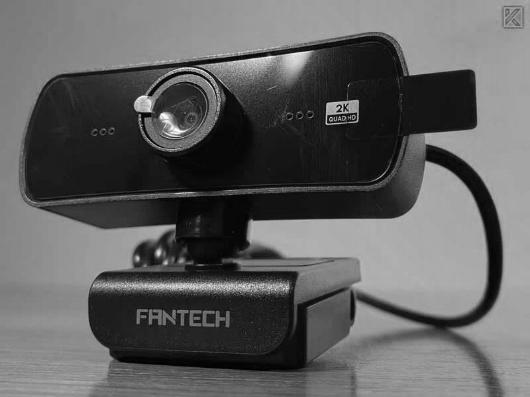
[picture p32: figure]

Table 6: FANTECH LUMINOUS C30 Web Camera – simplified datasheet view.

### 4.2. Motor Drivers

### 4.2.1. DC Motor Driver (IBT-4):

To control our powerful Ga25 drive motor, we selected the IBT-4 driver, which utilizes heavy-duty MOSFETs capable of handling extreme currents. This driver prevents voltage drops during active braking or sudden acceleration and protects the circuit from significant Back EMF.

IBT-4 DC Motor Driver

Type: High-current MOSFET H-Bridge DC motor driver

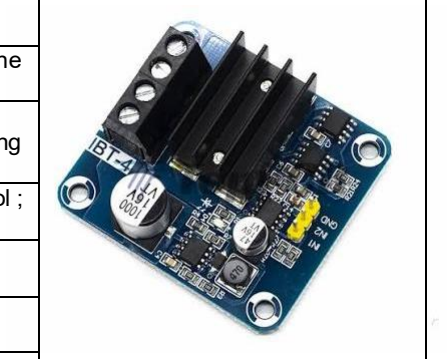
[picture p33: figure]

Operating Voltage: 5 V – 15 V (Perfectly accommodates the 11.1 V 3S Li-Po battery)
Current Capacity: Up to 50 A peak (Provides massive headroom for the Ga25 motor's 1.2 A stall current, preventing any thermal stress)
Control Signal: PWM inputs for speed and direction control ; Supports high PWM frequencies (up to 200 kHz)
Logic Level: 3.3 V and 5 V compatible (Directly interfaced with the STM32F411 3.3 V logic without level shifters) Protection Features: Over-voltage, under-voltage, over-temperature, and short-circuit protection
Mechanical: Equipped with a large aluminum heat sink for efficient passive thermal dissipation

Table 7: IBT-4 DC Motor Driver – simplified datasheet view.

### 4.2.2. Servo Driver (Waveshare Serial Bus Servo Driver):

To allow the STM32 to communicate with the DYNAMIXEL XL330 smart servo, we incorporated this specific driver board. It converts standard UART signals into the required half-duplex serial bus and provides clean, isolated power routing for the servo.

Waveshare Serial Bus Servo Driver

Type: UART to Half-Duplex Serial Bus Converter

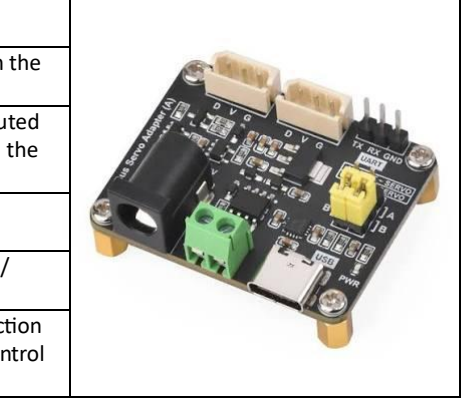
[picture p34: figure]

Logic Level: 3.3 V and 5 V compatible (Directly interfaces with the STM32F411 without level shifters)
Power Supply (Servo): Wide input voltage range (Power is routed directly to the servo, completely isolating motor current from the logic circuits)

Input Interface: Standard Full-Duplex UART (RX / TX / GND)

Output Interface: Half-Duplex Single-Wire Serial (DATA / VCC / GND)
Switching Mechanism: Hardware-level automatic TX/RX direction switching (Eliminates the need for a dedicated GPIO pin to control communication direction)

Table 8: Waveshare Serial Bus Servo Driver – simplified datasheet view.

### 4.3. Controllers and Microprocessors

Our system relies on a Hybrid Control Architecture that separates high-level processing tasks from low-level real-time motion control to ensure ultra-fast, zero-latency responsiveness.

### 4.3.1. Raspberry Pi 5 (8GB RAM):

4.3.1.1. System Role: Acts as the brain of the robot. It runs the operating system and executes the main control scripts (Python), alongside complex computer vision algorithms via OpenCV. It is responsible for processing camera frames, applying the Y-Axis depth-sorting algorithm for the red and green pillars, and subsequently sending strategic commands directly to the STM32 via serial communication (UART).

### 4.3.1.2. Technical Specifications: Powered by a Broadcom BCM2712 quad-core Cortex-A76

64-bit processor clocked at 2.4GHz, featuring a massive 8GB LPDDR4X RAM, along with ultra-fast high-speed I/O interfaces.
4.3.1.3. Justification: The Pi 5 delivers a massive leap in processing power compared to its predecessors. This high performance allows the robot to process 2K resolution images at high frame rates (FPS) without any computational bottlenecks, ensuring that dodging and cornering decisions are made in milliseconds and transmitted instantly over serial.

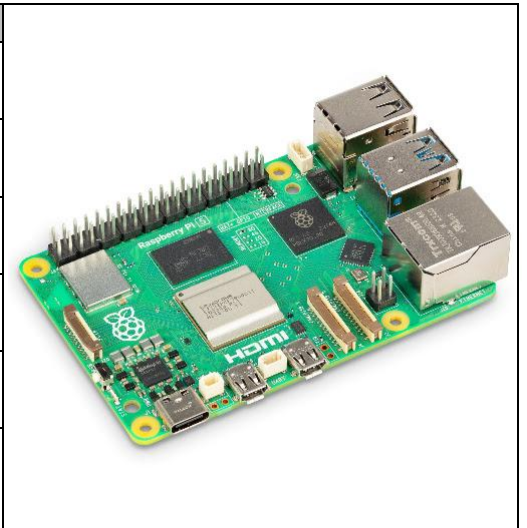
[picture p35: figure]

Raspberry Pi 5 (8GB RAM)
Type: High-Performance Single Board Computer (SBC) / Master
Node
Processor (CPU): Broadcom BCM2712, Quad-core 64-bit Arm Cortex-A76 @ 2.4GHz
Memory (RAM): 8GB LPDDR4X-4267 SDRAM (Provides massive headroom for high-resolution OpenCV image processing)

Operating Voltage: 5.0 V DC via USB-C

Key Interfaces: 2 × micro-HDMI, 2 × USB 3.0, 2 × USB 2.0, GPIO Header (utilizing UART TX/RX for STM32 communication) Cooling Requirement: Active Cooler (Heatsink + Fan) is highly recommended to prevent thermal throttling during continuous computer vision tasks
Mechanical: Standard Pi form factor (85 × 56 mm)

### 4.3.2. STM32F411 Microcontroller (BlackPill):

### 4.3.2.1. System Role: Serves as the muscular and operational node. It receives strategic

steering commands from the Raspberry Pi via UART and translates them into precise PWM signals for the motors. It also handles the hardware interrupts for the ultrasonic sensors and acquires data from the IMU.
4.3.2.2. Technical Specifications: Built on an ARM Cortex-M4 core running at 100 MHz, equipped with a Hardware Floating-Point Unit (FPU), 512KB of Flash memory, and 128KB of SRAM.

### 4.3.2.3. Justification: Advanced operating systems like Linux (used on the Pi) are not

designed for hard real-time tasks. The STM32 provides Deterministic Execution, ensuring that PID calculations, motor speed updates, and sensor readings occur with microsecond precision without jitter. Additionally, the integrated FPU significantly accelerates the complex floating-point decimal math required for the real-time control algorithms.

STM32F411 Microcontroller (BlackPill)

Type: 32-bit ARM Cortex-M4 Development Board

Processor (Core): ARM Cortex-M4 with Hardware Floating-Point Unit (FPU) @ 100 MHz
Memory: 512 KB Flash memory ; 128 KB SRAM
Operating Voltage: 3.3 V Logic Level (Board is safely powered via 5V from the XL4015 converter)
Key Interfaces: Multiple UART, I2C, and SPI buses ; Advanced hardware timers for highly accurate PWM generation ; External Interrupts (EXTI)
Mechanical: Compact DIP form factor (approx. 53 × 21 mm)

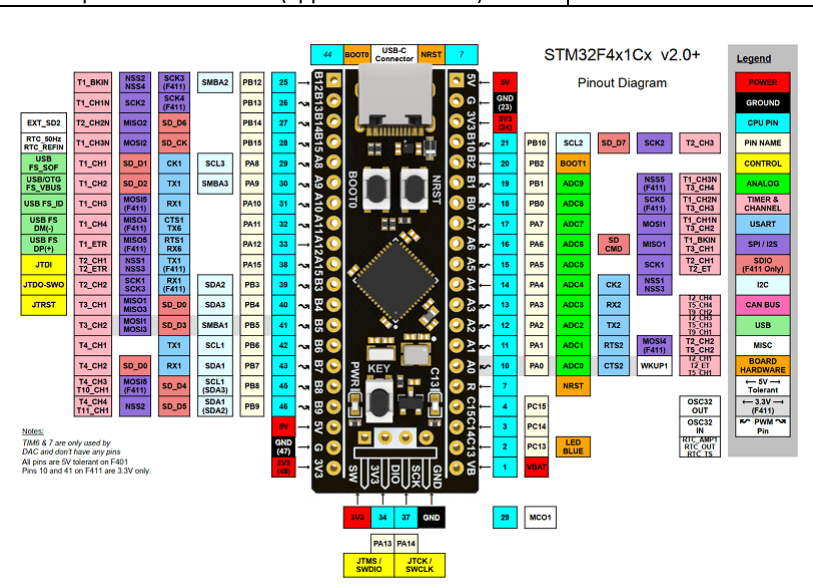
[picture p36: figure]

### 4.4. Power Management

We structured the electrical system based on the philosophy of "Separation of Power Domains" to guarantee absolute system stability:

Component | Quantity | Supply Voltage | Idle Current | Active Current | Peak/Stall Current
Raspberry Pi 5 (8GB) | 1 | 5.0 V | ~600–800 mA | ~1.5–2.0 A | up to 5.0 A
FANTECH LUMINOUS C30 | 1 | 5 V (via Pi USB) | – | ~150–250 mA | ~300 mA
STM32F411 (BlackPill) | 1 | 3.3 V / 5 V | ~10 mA | ~25–35 mA | ~50 mA
BNO085 IMU | 1 | 3.3 V | ~3 mA | ~10–15 mA | –
US-100 Ultrasonic Sensor | 3 | 5.0 V | < 2 mA | ~3–5 mA | –
VL53L0X Laser Sensor | 2 | 3.3 V – 5.0 V | < 5 µA | ~20 mA | ~40 mA
DYNAMIXEL XL330 Servo | 1 | 5.0 V | ~15 mA | ~150–300 mA | ~1.5 A
Ga25 DC Motor | 1 | 12 V | – | ~100–400 mA | ~1.2 A
IBT-4 Motor Driver | 1 | 5 V (Logic) / 12 V (Load) | ~2 mA | Adds driver losses to motor current | Handles up to 50 A peak
Waveshare Servo Driver | 1 | 5.0 V | ~2 mA (logic) | Servo load passes through | –
XL4015 DC-DC Converter | 1 | 12.0 V (in) / 5.0 V (out) | ~5 mA | Load dependent | Handles up to 5 A peak

Table 11: Electrical Component Current Specifications

### 4.4.1. Logic Power:

The Raspberry Pi and its connected camera are powered by a dedicated 20W Power Bank. This complete isolation prevents the operating system from suffering voltage drops or "brownouts" caused by sudden, massive current draws from the motors.

### 4.4.2. Actuator Power:

We utilize a Lithium-Polymer battery (Li-Po 3S 11.1V 2200mAh 30C) as the primary power source for the lower layer. The high discharge rate (30C) effortlessly supplies the necessary burst current for the DC motor and servo during critical moments (e.g., initial acceleration or sudden stops) without voltage sagging.

Battery:

Table 13: Li-Po 3S Battery (11.1 V, 2200 mAh, 30C) – simplified datasheet view

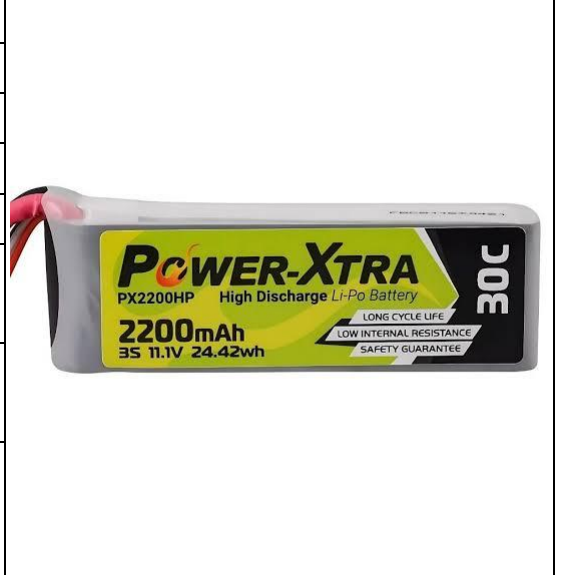
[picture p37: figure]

Li-Po 3S Battery (11.1 V, 2200 mAh, 30C)
Type: Lithium-Polymer (Li-Po) Rechargeable Battery Nominal Voltage: 11.1 V (3 Cells in series, 3.7 V per cell) Maximum Voltage: 12.6 V (Fully charged at 4.2 V per cell) Capacity: 2200 mAh (2.2 Ah)
Discharge Rate: 30C Continuous (Capable of safely delivering up to 66 A of continuous current)
Connectors: XT60 or T-Dean main power plug ; JST-XH balance plug for charging
Safety Notes: Requires a dedicated balance charger. Must not be discharged below 3.2 V per cell to prevent permanent chemical damage.

### 4.4.3. Voltage Regulation:

To safely power the STM32 microcontroller, Laser, and Ultrasonic sensors, we utilized an XL4015 DC-DC Step-Down Converter. It efficiently steps down the main battery voltage (11.1V) to a clean, regulated 5V, featuring high conversion efficiency and built-in thermal shutdown protection.

Converter:

XL4015 DC-DC Step-Down Converter Type: High-Efficiency DC-DC Step-Down (Buck) Converter Input Voltage Range: 8.0 V – 36.0 V (Perfectly accommodates the 11.1 V 3S Li-Po battery)
Output Voltage Range: 1.25 V – 32.0 V Adjustable (Calibrated to a stable 5.0 V for logic and sensors) Output Current: Up to 5.0 A maximum (with a heatsink) Switching Frequency: 180 kHz
Efficiency: Up to 96%
Protection Features: Built-in thermal shutdown, short-circuit protection, and current limiting

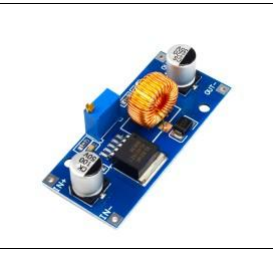
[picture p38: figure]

Table 12: XL4015 DC-DC Step-Down Converter – simplified datasheet view.

4.5. Custom Printed Circuit Board (PCB) To eliminate the unreliability of loose jumper wires and breadboards, we designed a custom Printed Circuit Board (PCB). The PCB acts as the central nervous system of the robot's hardware, cleanly routing power and data between the STM32 microcontroller, the sensor arrays (VL53L0X and US-100), the motor drivers (IBT-4
and | Waveshare), | and | the | XL4015 | power | management | module.

4.5.1.Schematic Design The schematic was engineered to ensure complete isolation between the logic circuits and the high-current actuators. It includes properly sized traces for power delivery, pull-up resistors for the I2C lines (IMU and Laser sensors), and organized header pins for direct, secure connections.

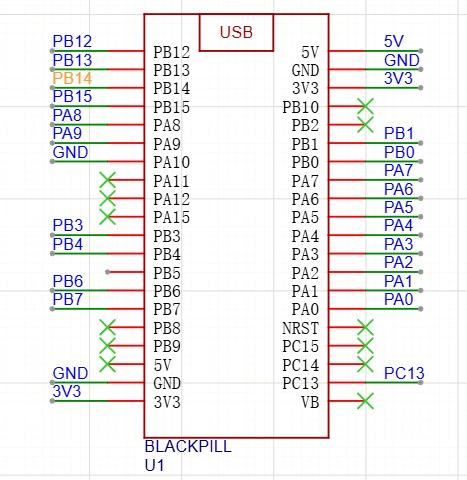
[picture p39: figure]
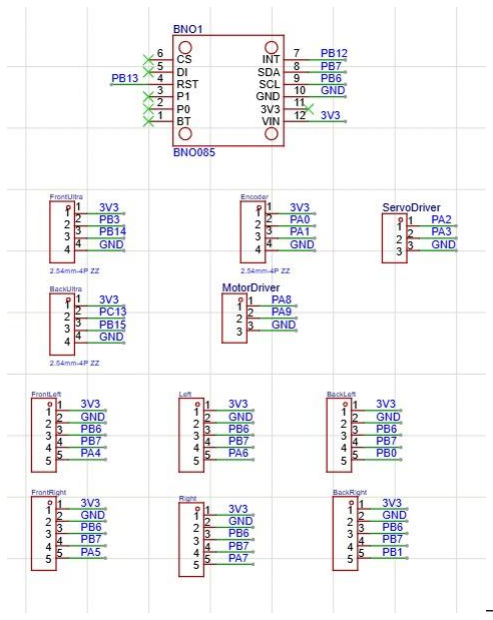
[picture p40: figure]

### 4.5.2. PCB Layout & Routing The physical board layout was designed with careful

consideration for electromagnetic interference (EMI) and power dissipation. The XL4015 step-down converter and the STM32 BlackPill are strategically placed to minimize signal travel distance. Ground pours (Copper Pours) were utilized extensively across the board to provide a common ground reference and dissipate any excess heat.


4.5.3.

## 5.Obstacle Management

Our navigation system relies on real-time sensor evaluation and precise image classification to smoothly guide the robot through obstacles and successfully complete the three laps.

### 5.1. System Architecture & Communication

Instead of using heavy middleware, we adopted a lightweight, ultra-fast Master-Slave architecture relying on direct serial communication (UART Protocol) between the processing units:

5.1.1.Master Node:

Represented by the Raspberry Pi 5 running a Python script. It captures frames, processes them via OpenCV, and determines strategic commands (e.g., TURN_LEFT or DODGE_RIGHT).

5.1.2.Execution Node:

Represented by the STM32 microcontroller. It receives these short string commands and immediately integrates them into a Non-blocking Finite State Machine (FSM) to update motor speeds and PID offsets, without halting distance or IMU sensor readings. This approach ensures high-frequency data flow with near-zero latency.

### 5.2. Open Challenge

In this challenge, the goal is to complete 3 laps without hitting the walls in the shortest possible time. We rely on a wall-following algorithm using ultrasonic sensors, minimizing the error between the right and left distances to zero using a PID controller.

5.2.1. "Direction Lock" Algorithm:

The camera does not rely on colors to determine the turn direction at every corner; instead, it uses a smart locking mechanism. Upon starting, the camera monitors the floor; if it detects an Orange line first, the system locks the direction as "Clockwise" (CW). If a Blue line is detected, it locks as "Counter-Clockwise" (CCW). For the subsequent 11 corners, the robot executes the turn based on this locked direction as soon as any color is seen, entirely preventing visual confusion and ensuring track stability.

5.3.Image Processing

To avoid color fluctuations due to lighting, we convert the frames captured by the tilt-down camera from the RGB format to the HSV color space.

### 5.3.1. Region of Interest & Contouring:

We apply masks to isolate the four colors (Blue, Orange, Red, Green), utilize morphological filters to remove noise, and extract Bounding Boxes for each element to determine its position and dimensions on the screen.

### 5.4. Obstacle Challenge

While corners rely on the pixel density of the floor lines, pillars require high spatial accuracy to determine dodging priority. To overcome complex scenarios (like having both red and green pillars in the same frame), we developed the Y-Axis Depth Sorting algorithm:

The algorithm collects the coordinates of all detected pillars and sorts them in descending order based on the lowest point of their bounding box ($bottom\_y$).

All distant pillars are ignored, and the system interacts only with the pillar having the highest $Y$ value (the one closest to the front of the robot).

If the closest pillar is Red, the Raspberry Pi sends a DODGE_RIGHT command. The STM32 translates this command into a dynamic bias ($Lane\_Offset$) within the distance sensors' PID equation, smoothly hugging the right wall. For a Green pillar, DODGE_LEFT is sent. This dynamic maneuver allows the robot to perform professional, continuous Slalom movements without needing to stop.

### 5.5. Performance Videos

These are the links to the YouTube videos of our robot successfully completing the challenges:

### 5.5.1. Open Challenge:

[Link] (https://www.youtube.com/watch?v=mKhY2ytfqhQ)

### 5.5.2. Obstacle Challenge:

[Link] (https://www.youtube.com/watch?v=mKhY2ytfqhQ)

### 5.6. Problems We Encountered

### 5.6.1. Camera Field of View Limitation

### 5.6.1.1. Problem: In the early development stages, we used the standard

Raspberry Pi camera. However, its narrow Field of View (FOV) made it difficult for the robot to see the full width of the track or detect peripheral pillars in a timely manner.

### 5.6.1.2. Solution: We replaced it with the FANTECH LUMINOUS C30 web

camera. This camera features a wide-angle lens and crisp resolution, enabling the computer vision algorithms to capture all surrounding details and recognize corners and obstacles from a safe, early distance.

### 5.6.2. Ackermann Steering Angle Limitations

### 5.6.2.1. Problem: During maneuver testing and tight pillar passing, we

encountered limitations in the maximum steering angle achievable by our initial Ackermann steering mechanism. This increased the robot's turning radius, dangerously pushing it towards the outer walls.

### 5.6.2.2. Solution: We redesigned the steering knuckles and tie rods using

SolidWorks and 3D-printed them with geometrically optimized pivot points and lever lengths. This adjustment significantly increased the Range of

Motion for the front wheels, allowing the robot to make sharp, large-angle turns smoothly while maintaining the correct Ackermann intersection to prevent tire scrub.

### 5.6.3. Flickering

### 5.6.3.1. Problem: Variations in room lighting and the frequency of fluorescent

lamps caused flickering in the frames captured by the camera, which negatively impacted the stability of our color masks.

### 5.6.3.2. Solution: We disabled Auto White Balance and programmatically

adjusted the camera's shutter speed and exposure via OpenCV to synchronize with the ambient lighting frequency, resulting in perfectly stable and clean frames.

### 5.6.4. Failing to Synchronize Data Flow Between Processors

### 5.6.4.1. Problem: The Raspberry Pi sent a continuous, heavy stream of data

over serial (UART) to the STM32, leading to buffer overflow and a delayed motor response to camera detections.

### 5.6.4.2. Solution: We abandoned continuous streaming and designed a

lightweight communication protocol that sends short, event-based commands (e.g., TURN_LEFT) only when the state changes. We also implemented a non-blocking Finite State Machine (FSM) in the STM32 to ensure instantaneous serial commands are read without halting other vital operations.

### 5.6.5. Pillars Contours Merging

### 5.6.5.1. Problem: In track sections with closely placed pillars, the low camera

perspective caused the pillars' contours to merge in the frame. The algorithm misidentified them as a single large obstacle, leading to traversal failures.

### 5.6.5.2. Solution: We modified the mechanical design by elevating the camera

to the third layer of the robot and optimizing its tilt-down angle. This elevation provided excellent visual separation between the pillars and allowed our Y-Axis Depth Sorting algorithm to function with pinpoint accuracy.

## 6.Improvements and future modifications

### 6.1. Mobility Management 6.1.1. Aluminum CNC Upgrade:

Although the 3D-printed parts are lightweight and currently serve their purpose, we plan to replace the Ackermann steering knuckles and motor mounts with CNC-machined aluminum parts. This will eliminate any mechanical flex in the joints at high speeds, thereby enhancing steering precision and extending the chassis' lifespan.

### 6.1.2. Differential Upgrade:

We aim to replace the current differential with a fully sealed metal differential containing lubricating fluid to reduce internal friction and power loss. This upgrade will significantly improve the efficiency of torque transfer from the Ga25 motor to the silicone wheels.

### 6.2. Power and Sense Management 6.2.1. Battery Management System (BMS):

We plan to integrate a smart BMS module into our custom PCB. This unit will monitor individual cell voltages of the Li-Po battery and the real-time current draw. This data will be transmitted via UART to the Raspberry Pi, allowing the system to dynamically cap the motor's top speed to prevent battery fatigue or sudden voltage drops.

### 6.2.2. LiDAR Integration:

Despite the efficiency of the VL53L0X and US-100 sensors, upgrading to a 2D LiDAR sensor (e.g., RPLIDAR) will provide a 360-degree point cloud map. This will reduce the number of discrete sensors required and offer unparalleled accuracy for the robot's localization within the track.

### 6.3. Obstacle Management 6.3.1. Deep Learning for Vision:

Given the massive processing power of our Raspberry Pi 5 (8GB), we plan to upgrade our image processing pipeline. Instead of relying on OpenCV HSV color masks, we aim to deploy lightweight Deep Learning models (such as YOLO). This will make the detection system completely immune to drastic lighting changes or color distortions on the pillars.

### 6.3.2. Optimization of the Selected Path:

According to WRO rules, pillar placements remain fixed across all three laps. We plan to develop a "Path Caching" algorithm during the relatively slower first lap to memorize the colors and coordinates of the pillars. In the second and third laps, the robot will utilize this memory to navigate the obstacles at maximum speed without evaluating the camera frames from scratch in every section.

## 7. Conclusion

Throughout this project, our goal was never simply to build a robot that completes the track, but to engineer a system where every component was chosen for a defensible reason and every subsystem was validated through testing rather than assumption.

The defining decision of our design was the Hybrid Control Architecture: separating high-level perception on the Raspberry Pi 5 from hard real-time execution on the STM32F411. This split allowed each processor to do what it does best — computer vision without timing pressure, and deterministic PID control without operating-system jitter — and directly resolved the serial buffer overflow that had been delaying our motor response to camera detections.

Equally important was our commitment to iterative refinement. Nearly every subsystem in this report exists in its current form because an earlier version failed under test. Our steering knuckles were redesigned in SolidWorks after we hit the limits of our original Ackermann geometry. Our camera moved to the third layer only after merged pillar contours revealed that a low perspective was costing us spatial separation. Our communication protocol was rewritten from continuous streaming to event-based commands after buffer overflows appeared. Each of these problems taught us more than a first-attempt success would have.

Beyond the technical outcomes, this project developed our capabilities in mechanical design, PCB layout, embedded firmware, computer vision, and — critically — the systems thinking required to make these disciplines work together. The improvements outlined in Section 6 represent our clear roadmap forward, and we are confident that the foundation documented here is robust enough to support them.

We are proud of what team X-CUTE has built, and we look forward to competing in WRO 2026.

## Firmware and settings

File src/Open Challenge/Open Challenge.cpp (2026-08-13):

#include <Arduino.h>
#include <Wire.h>
#include <Dynamixel2Arduino.h>
#include <Adafruit_BNO08x.h>


const int IN1 = PA8;
const int IN2 = PA9;

HardwareSerial SerialDXL(PA3, PA2); // TX-RX
const int8_t DXL_DIR_PIN = -1;
Dynamixel2Arduino dxl(SerialDXL, DXL_DIR_PIN);

const uint8_t DXL_ID = 1;
const uint32_t DXL_BAUDRATE = 57600;

int SERVO_CENTER = 2048;
int SERVO_OFFSET = 400; // أقصى زاوية انحراف

unsigned short _RoundNumber = 0; // متغير لتتبع عدد الجولات التي أكملها الروبوت
bool finshed = false;

const int echo_Ultra4 = PC13;
const int Trig_Ultra4 = PB15;

// Right
const int echo_Ultra5 = PB14;
const int Trig_Ultra5 = PB3;

// Front 
const int echo_UltraFront = PA6;
const int Trig_UltraFront = PA4;

volatile unsigned long startTimeLeft = 0;
volatile unsigned long startTimeRight = 0;
volatile unsigned long startTimeFront = 0; 

volatile float distanceLeft = 0;
volatile float distanceRight = 0;
volatile float distanceFront = 0; 

unsigned long lastTriggerTimeLeft = 0;
unsigned long lastTriggerTimeRight = 0;
unsigned long lastTriggerTimeFront = 0; 

bool flagLeft = true;
bool flagRight = true;
bool flagFront = true; 



float cumulativeYaw = 0.0;    // الزاوية التراكمية المستمرة (تزيد وتنقص بدون حد 180)
float lastRawYaw = 0.0;       // القراءة الخام السابقة
bool isFirstGyroRead = true;  // لضبط أول قراءة
float startTurnYaw = 0.0;     // نقطة مرجعية لمراقبة زاوية الانعطاف الحالي


// ==========================================
// 3. إعدادات الجايروسكوب BNO085 والتصفير البرمجي
// ==========================================
#define BNO08X_RESET PB13
#define BNO08X_INT PB12
// (SDA = PB7, SCL = PB6) يتم إعدادها في الـ Setup

Adafruit_BNO08x bno08x(BNO08X_RESET);
sh2_SensorValue_t sensorValue;

float currentYaw = 0.0;
float yawOffset = 0.0; // المتغير الذي سيحفظ نقطة الصفر الوهمية

bool flag = true; // متغير لتحديد ما إذا كان يجب إعادة تهيئة الجايروسكوب بعد إعادة التشغيل
// دالة لتحديث قراءة الجايرو وتحويل الـ Quaternion إلى زاوية Yaw
void updateGyro() {

  if (bno08x.wasReset()) {
    bno08x.enableReport(SH2_GAME_ROTATION_VECTOR, 10000);
  }

if (flag)
{
bno08x.hardwareReset();
delay(500);
flag = false;

} 

  if (bno08x.getSensorEvent(&sensorValue)) {
    if (sensorValue.sensorId == SH2_GAME_ROTATION_VECTOR) {
      float qr = sensorValue.un.gameRotationVector.real;
      float qi = sensorValue.un.gameRotationVector.i;
      float qj = sensorValue.un.gameRotationVector.j;
      float qk = sensorValue.un.gameRotationVector.k;

      float sqi = qi * qi;
      float sqj = qj * qj;
      float sqk = qk * qk;
      
      // القراءة الخام بين -180 و +180
      float rawYaw = atan2(2.0 * (qi * qj + qk * qr), (sqi - sqj - sqk + qr * qr)) * 180.0 / PI;

      if (isFirstGyroRead) {
        lastRawYaw = rawYaw;
        isFirstGyroRead = false;
      }

      // حساب الفرق ومعالجة قفزة الحدود (-180 إلى +180)
      float delta = rawYaw - lastRawYaw;
      while (delta > 180.0) delta -= 360.0;
      while (delta < -180.0) delta += 360.0;

      cumulativeYaw += delta; // إضافة التغير للزاوية التراكمية
      lastRawYaw = rawYaw;
    }
  }
}

// دالة لالتقاط نقطة الصفر الحالية
void zeroGyro() {
  yawOffset = currentYaw;
}

// دالة لمعرفة الزاوية التي قطعها الروبوت منذ آخر تصفير
float getRelativeYaw() {
  float diff = currentYaw - yawOffset;
  while (diff > 180.0) diff -= 360.0;
  while (diff < -180.0) diff += 360.0;
  return diff;
}

// ==========================================
// 4. متغيرات الـ PID وحالة الروبوت (State Machine)
// ==========================================
float Kp = 3;
float Kd = 1.5;
float Ki = 0.05;

float previousError = 0;
float integral = 0;
unsigned long lastTime = 0;

enum DriveState
{
  WALL_FOLLOWING,
  WAITING_FOR_LEFT_CORNER,
  WAITING_FOR_RIGHT_CORNER,
  TURNING_LEFT,
  TURNING_RIGHT
};

DriveState currentState = WALL_FOLLOWING;

// ==========================================
// 5. دوال المقاطعة (ISR) للحساسات
// ==========================================
void leftEchoISR()
{
  if (digitalRead(echo_Ultra4) == HIGH) {
    startTimeLeft = micros();
  } else {
    distanceLeft = (micros() - startTimeLeft) * 0.0343 / 2.0;
    flagLeft = true;
  }
}


void rightEchoISR()
{
  if (digitalRead(echo_Ultra5) == HIGH) {
    startTimeRight = micros();
  } else {
    distanceRight = (micros() - startTimeRight) * 0.0343 / 2.0;
    flagRight = true;
  }
}


void frontEchoISR()
{
  if (digitalRead(echo_UltraFront) == HIGH) {
    startTimeFront = micros();
  } else {
    distanceFront = (micros() - startTimeFront) * 0.0343 / 2.0;
    flagFront = true;
  }
}


void Turn(int turn_value)
{
  dxl.setGoalPosition(DXL_ID, turn_value);
}


void setMotor(int speed)
{
  if (speed > 0)
  {
    analogWrite(IN1, speed);
    analogWrite(IN2, 0);
  }
  else if (speed < 0)
  {
    analogWrite(IN1, 0);
    analogWrite(IN2, abs(speed)); // الدوران للخلف للفرملة
  }
  else
  {
    analogWrite(IN1, 0);
    analogWrite(IN2, 0);
  }
}


void WallFolwing_PID(float dt, unsigned long currentTime, int speed)
{
  setMotor(speed); 

  float safeLeft = (distanceLeft > 0 && distanceLeft < 150) ? distanceLeft : 150;
  float safeRight = (distanceRight > 0 && distanceRight < 150) ? distanceRight : 150;

  float error = safeRight - safeLeft;
  float P_out = Kp * error;

  integral += (error * dt);
  if (integral > 50.0) integral = 50.0;
  else if (integral < -50.0) integral = -50.0;

  if ((error > 0 && previousError < 0) || (error < 0 && previousError > 0)) {
    integral = 0;
  }

  float I_out = Ki * integral;
  float derivative = (error - previousError) / dt;
  float D_out = Kd * derivative;

  previousError = error;

  float totalOutput = P_out + I_out + D_out;

  if (totalOutput > SERVO_OFFSET) totalOutput = SERVO_OFFSET;
  else if (totalOutput < -SERVO_OFFSET) totalOutput = -SERVO_OFFSET;

  Turn(SERVO_CENTER + totalOutput);
  lastTime = currentTime;
}


void triggerUltrasonicSensors(unsigned long currentTime)
{
  if (flagLeft || currentTime - lastTriggerTimeLeft > 25)
  {
    flagLeft = false;
    digitalWrite(Trig_Ultra4, LOW); delayMicroseconds(2);
    digitalWrite(Trig_Ultra4, HIGH); delayMicroseconds(10);
    digitalWrite(Trig_Ultra4, LOW);
    lastTriggerTimeLeft = currentTime;
  }
  if (flagRight || currentTime - lastTriggerTimeRight > 25)
  {
    flagRight = false;
    digitalWrite(Trig_Ultra5, LOW); delayMicroseconds(2);
    digitalWrite(Trig_Ultra5, HIGH); delayMicroseconds(10);
    digitalWrite(Trig_Ultra5, LOW);
    lastTriggerTimeRight = currentTime;
  }
  if (flagFront || currentTime - lastTriggerTimeFront > 25)
  {
    flagFront = false;
    digitalWrite(Trig_UltraFront, LOW); delayMicroseconds(2);
    digitalWrite(Trig_UltraFront, HIGH); delayMicroseconds(10);
    digitalWrite(Trig_UltraFront, LOW);
    lastTriggerTimeFront = currentTime;
  }
}


bool isRound()
{
  static unsigned short TurnCounter = 0;
  TurnCounter++;

  if(TurnCounter == 4)
  {
    TurnCounter = 0;
    return true;
  }
  else
  {
    return false;
  }
}


int getRoundNumber()
{
  static unsigned short RoundCounter = 0;

  if(isRound())
    {
      RoundCounter++;
    }

      return RoundCounter;
}

void UpdateDriveState(float dt, unsigned long currentTime)
{
  updateGyro();

  // حالة: انتظار اختفاء الجدار الأيسر
  if (currentState == WAITING_FOR_LEFT_CORNER)
  {
    WallFolwing_PID(dt, currentTime, 600);    
    if (distanceLeft >= 100 || distanceFront < 45) 
    {
      setMotor(800);
      startTurnYaw = cumulativeYaw; // التقاط الزاوية الحالية قبل بدء الدوران
      currentState = TURNING_LEFT;
    }
  }

  // حالة: التنفيذ الفعلي للالتفاف لليسار
  else if (currentState == TURNING_LEFT)
  {
    setMotor(800);
    Turn(SERVO_CENTER - SERVO_OFFSET);  

    // قياس الزاوية المقطوعة منذ بدء الدوران
    if (abs(cumulativeYaw - startTurnYaw) >= 89.0) 
    {
      _RoundNumber = getRoundNumber();
      currentState = WALL_FOLLOWING;
      integral = 0;      
      previousError = 0; 
      lastTime = millis(); 
    }
  }

  // حالة: انتظار اختفاء الجدار الأيمن
  else if (currentState == WAITING_FOR_RIGHT_CORNER)
  {
    WallFolwing_PID(dt, currentTime, 600);
    
    if (distanceRight >= 100 || distanceFront < 45)
    {
      setMotor(800);
      startTurnYaw = cumulativeYaw; // التقاط الزاوية الحالية قبل بدء الدوران
      currentState = TURNING_RIGHT;
    }
  }

  // حالة: التنفيذ الفعلي للالتفاف لليمين
  else if (currentState == TURNING_RIGHT)
  {
    setMotor(800);
    Turn(SERVO_CENTER + SERVO_OFFSET); // تم تصحيح الاتجاه إلى (+) لليمين

    // قياس الزاوية المقطوعة منذ بدء الدوران
    if (abs(cumulativeYaw - startTurnYaw) >= 89.0) 
    {
      _RoundNumber = getRoundNumber();
      currentState = WALL_FOLLOWING;
      integral = 0;
      previousError = 0;
      lastTime = millis();
    }
  }

  // حالة: المشي بخط مستقيم وتتبع الجدران
  else if (currentState == WALL_FOLLOWING)
  {
    WallFolwing_PID(dt, currentTime, 900);
  }
}

void setup()
{

  Serial.begin(115200);

  // إعداد دبابيس الألتراسونيك
  pinMode(Trig_Ultra4, OUTPUT);
  pinMode(echo_Ultra4, INPUT_PULLDOWN);
  pinMode(Trig_Ultra5, OUTPUT);
  pinMode(echo_Ultra5, INPUT_PULLDOWN);
  pinMode(Trig_UltraFront, OUTPUT);
  pinMode(echo_UltraFront, INPUT_PULLDOWN);
  
  pinMode(PA0, INPUT_PULLUP);
  
  // ربط المقاطعات
  attachInterrupt(digitalPinToInterrupt(echo_Ultra4), leftEchoISR, CHANGE);
  attachInterrupt(digitalPinToInterrupt(echo_Ultra5), rightEchoISR, CHANGE);
  attachInterrupt(digitalPinToInterrupt(echo_UltraFront), frontEchoISR, CHANGE);

  // إعداد المحرك الدفع
  pinMode(IN1, OUTPUT);
  pinMode(IN2, OUTPUT);
  analogWriteFrequency(20000);
  analogWriteResolution(10);

  // إعداد السيرفو Dynamixel
  dxl.begin(DXL_BAUDRATE);
  dxl.setPortProtocolVersion(2.0);
  dxl.torqueOff(DXL_ID);
  dxl.setOperatingMode(DXL_ID, OP_POSITION);
  dxl.torqueOn(DXL_ID);
  Turn(SERVO_CENTER);

  // إعداد الجايروسكوب
  Wire.setSCL(PB6);
  Wire.setSDA(PB7);
  Wire.begin();

  
  if (!bno08x.begin_I2C(0x4A, &Wire, BNO08X_INT)) {
    SerialUSB.println("Failed to find BNO08x chip");
    while(true)
    {

    }

  } else {
    SerialUSB.println("BNO085 Initialized!");
    bno08x.enableReport(SH2_GAME_ROTATION_VECTOR, 10000);
  }

  lastTime = millis();

  Serial.setTimeout(5);

  // انتظار CRUISE_INTO_ZONE_MSضغطة الزر للبدء
  // delay(5000);
  while (digitalRead(PA0))
  {
  }
}


bool finished = false;
bool stopTimerStarted = false;
unsigned long stopStartTime = 0;

void loop()
{


const unsigned long CRUISE_INTO_ZONE_MS = 1200; 


  unsigned long currentTime = millis();
  float dt = (currentTime - lastTime) / 1000.0;

  if (dt <= 0.0) return; // حماية من قسمة الصفر

  // إطلاق نبضات الألتراسونيك بشكل دوري وغير معطل
  triggerUltrasonicSensors(currentTime);

  
  if (Serial.available())
  {
    String incomingData = Serial.readStringUntil('\n');
    incomingData.trim();

    if (currentState == WALL_FOLLOWING)
    {
      if (incomingData.indexOf("TURN_LEFT") != -1)
      {
        currentState = WAITING_FOR_LEFT_CORNER; 
        // setMotor(-400);
        // delay(2000);
      }
      else if (incomingData.indexOf("TURN_RIGHT") != -1)
      {
        currentState = WAITING_FOR_RIGHT_CORNER; 
        // setMotor(00);
        // delay(2000);
        
      }
    }
  }


  if(_RoundNumber < 3)
 {
    UpdateDriveState(dt, currentTime);
 }
  else if(!finished)
 {
    if (!stopTimerStarted)
    {
        stopStartTime = currentTime;
        stopTimerStarted = true;
        // اختياري: خلي الروبوت يمشي بسرعة ثابتة وبسيطة لحد ما ينزل بمنطقة التوقف
        WallFolwing_PID(dt, currentTime, 400);  // سرعة منخفضة، لسا PID شغال وآمن
    }
    else if (currentTime - stopStartTime < CRUISE_INTO_ZONE_MS)
    {
        WallFolwing_PID(dt, currentTime, 400);  // استمر بالمشي المحكوم لحد ما تخلص المدة
    }
    else
    {

        setMotor(0);
        Turn(SERVO_CENTER);
        finished = true; 
        while(1)
        {

        }

    }
 }
  
}

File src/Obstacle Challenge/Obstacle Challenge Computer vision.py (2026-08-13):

"""
كود رؤية حاسوبية لكشف المكعبات (أحمر/أخضر) - مسابقة WRO 2026 Future Engineers
------------------------------------------------------------------------
المنطق:
- مكعب أخضر  -> استدارة يسار (LEFT)
- مكعب أحمر  -> استدارة يمين (RIGHT)
- ما في مكعب -> استمرار للأمام (FORWARD)

يعتمد على تحويل الصورة لفضاء الألوان HSV لأنه أدق وأكثر ثباتاً
من RGB بالنسبة لتغيرات الإضاءة (مهم جداً بإضاءة الحلبة/الترابيزة).

يمكنك تعديل نطاقات الألوان (HSV ranges) حسب إضاءة مكان التدريب عندك.
"""

import cv2
import numpy as np
import serial
import time

# ==========================================================
# 0) إعدادات السيريال (UART) للاتصال مع STM32
# ==========================================================
# غيّر SERIAL_PORT حسب جهازك:
#   ويندوز:  "COM3", "COM4" ... (شوفه من Device Manager)
#   لينكس:   "/dev/ttyUSB0" أو "/dev/ttyACM0"
#   ماك:     "/dev/tty.usbserial-XXXX"
SERIAL_PORT = "COM4"
BAUD_RATE = 115200          # لازم يكون نفس الـ baud rate المضبوط بكود STM32 (USART)

# الأوامر اللي رح تنبعت لـ STM32 - حرف واحد لكل قرار (أخف وأسرع إرسال)
CMD_LEFT = b'L'
CMD_RIGHT = b'R'
CMD_FORWARD = b'F'

ser = None  # متغير الاتصال السيريال، رح يتفتح بالـ main()


def init_serial():
    """يحاول يفتح بورت السيريال، وإذا فشل يكمل الكود بدون STM32 (وضع تجربة فقط)"""
    global ser
    try:
        ser = serial.Serial(SERIAL_PORT, BAUD_RATE, timeout=1)
        time.sleep(2)  # وقت مطلوب عادةً حتى يجهز البورت بعد الفتح
        print(f"تم فتح السيريال على {SERIAL_PORT} بسرعة {BAUD_RATE}")
    except serial.SerialException as e:
        print(f"تحذير: ما قدرت أفتح السيريال ({e}). رح يشتغل الكود بدون إرسال لـ STM32.")
        ser = None


def send_serial_command(cmd_bytes):
    """يبعت أمر واحد عبر السيريال لو البورت مفتوح"""
    if ser is not None and ser.is_open:
        try:
            ser.write(cmd_bytes)
        except serial.SerialException as e:
            print(f"خطأ بالإرسال عبر السيريال: {e}")


# ==========================================================
# 1) إعدادات نطاقات الألوان (HSV) - عدّلها حسب الإضاءة عندك
# ==========================================================
# اللون الأحمر بياخد نطاقين لأنه يلف حوالين 0/180 بمقياس Hue في OpenCV
LOWER_RED_1 = np.array([0, 100, 80])
UPPER_RED_1 = np.array([10, 255, 255])
LOWER_RED_2 = np.array([170, 100, 80])
UPPER_RED_2 = np.array([180, 255, 255])

LOWER_GREEN = np.array([40, 70, 60])
UPPER_GREEN = np.array([85, 255, 255])

# أقل مساحة (بالبكسل) عشان نعتبر الكشف "مكعب حقيقي" مش ضوضاء
MIN_CONTOUR_AREA = 800

# مسافة تقريبية: كل ما زادت مساحة الكونتور كل ما كان المكعب أقرب للروبوت
CLOSE_AREA_THRESHOLD = 6000  # عدّلها حسب تجربتك العملية

# دقة الكاميرا - قللها إذا بدك أداء أسرع (أقل تأخير/لاق)
# دقة أوطى = معالجة أسرع بس تفاصيل أقل، دقة أعلى = أدق بس أبطأ
FRAME_WIDTH = 640
FRAME_HEIGHT = 480


def get_color_mask(hsv_frame):
    
    mask_green = cv2.inRange(hsv_frame, LOWER_GREEN, UPPER_GREEN)

    mask_red_1 = cv2.inRange(hsv_frame, LOWER_RED_1, UPPER_RED_1)
    mask_red_2 = cv2.inRange(hsv_frame, LOWER_RED_2, UPPER_RED_2)
    mask_red = cv2.bitwise_or(mask_red_1, mask_red_2)

    # تنظيف الضوضاء (فتح ثم إغلاق)
    kernel = np.ones((5, 5), np.uint8)
    mask_green = cv2.morphologyEx(mask_green, cv2.MORPH_OPEN, kernel)
    mask_green = cv2.morphologyEx(mask_green, cv2.MORPH_CLOSE, kernel)

    mask_red = cv2.morphologyEx(mask_red, cv2.MORPH_OPEN, kernel)
    mask_red = cv2.morphologyEx(mask_red, cv2.MORPH_CLOSE, kernel)

    return mask_green, mask_red


def find_largest_cube(mask):
    """يلاقي أكبر كونتور بالقناع ويرجع (مركزه، مساحته، صندوقه) أو None"""
    contours, _ = cv2.findContours(mask, cv2.RETR_EXTERNAL, cv2.CHAIN_APPROX_SIMPLE)
    if not contours:
        return None

    largest = max(contours, key=cv2.contourArea)
    area = cv2.contourArea(largest)

    if area < MIN_CONTOUR_AREA:
        return None

    x, y, w, h = cv2.boundingRect(largest)
    center_x = x + w // 2
    center_y = y + h // 2

    return {
        "center": (center_x, center_y),
        "area": area,
        "box": (x, y, w, h),
    }


def decide_direction(frame):
    """
    يحلل فريم واحد ويرجع القرار:
    'LEFT'  -> مكعب أخضر
    'RIGHT' -> مكعب أحمر
    'FORWARD' -> ما في مكعب واضح
    مع معلومات إضافية للتصحيح (debug)
    """
    hsv = cv2.cvtColor(frame, cv2.COLOR_BGR2HSV)
    mask_green, mask_red = get_color_mask(hsv)

    green_cube = find_largest_cube(mask_green)
    red_cube = find_largest_cube(mask_red)

    decision = "FORWARD"
    chosen = None
    color_name = None

    # إذا في المكعبين سوا، ناخد الأقرب (الأكبر مساحة) لأنه هو اللي لازم نتعامل معه أول
    if green_cube and red_cube:
        if green_cube["area"] >= red_cube["area"]:
            chosen, decision, color_name = green_cube, "LEFT", "GREEN"
        else:
            chosen, decision, color_name = red_cube, "RIGHT", "RED"
    elif green_cube:
        chosen, decision, color_name = green_cube, "LEFT", "GREEN"
    elif red_cube:
        chosen, decision, color_name = red_cube, "RIGHT", "RED"

    return decision, chosen, color_name, mask_green, mask_red


def draw_debug(frame, chosen, decision, color_name):
    """يرسم صندوق حول المكعب المكتشف والقرار فوق الصورة (للتجربة على الشاشة)"""
    if chosen:
        x, y, w, h = chosen["box"]
        color_bgr = (0, 255, 0) if color_name == "GREEN" else (0, 0, 255)
        cv2.rectangle(frame, (x, y), (x + w, y + h), color_bgr, 2)
        cv2.putText(frame, f"{color_name} -> {decision}", (x, y - 10),
                    cv2.FONT_HERSHEY_SIMPLEX, 0.7, color_bgr, 2)
    else:
        cv2.putText(frame, "FORWARD", (20, 40),
                    cv2.FONT_HERSHEY_SIMPLEX, 0.9, (255, 255, 255), 2)
    return frame


# ==========================================================
# 2) دالة اتخاذ القرار الفعلي بتربطها بموتورات الروبوت
#    عدّل محتوى الدالة حسب مكتبة التحكم عندك (GPIO / Serial / PWM ...)
# ==========================================================
def send_command_to_robot(decision):
    if decision == "LEFT":
        print(">> أمر: استدارة يسار (مكعب أخضر) -> إرسال 'L'")
        send_serial_command(CMD_LEFT)
    elif decision == "RIGHT":
        print(">> أمر: استدارة يمين (مكعب أحمر) -> إرسال 'R'")
        send_serial_command(CMD_RIGHT)
    else:
        print(">> أمر: استمرار للأمام -> إرسال 'F'")
        send_serial_command(CMD_FORWARD)
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
